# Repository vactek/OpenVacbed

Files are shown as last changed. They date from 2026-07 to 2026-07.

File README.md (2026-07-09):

# Guide

Work in progress

This is the guide to the Open Source VacBed by VacTek.
It works well with our AutoRegulator

TODO link to AutoRegulator

## Preface

This guide assumes you know what a vacbed is, how it works, and that you want to build one.
Sourcing is US-oriented. And, as you've heard 1000x before: Never use it alone!

### Features

+ Everything you need to experience a vacbed, and probably more!
+ Air-tight & quiet vac
+ Collapsible
+ Mask that takes pressure off the nose

## Supplies & Tools List

### General Tools

+ Sandpaper, around 150 grit
+ Silver Sharpie (for marking on PVC and latex; it washes off with Heptane) [Link](https://a.co/d/dIjm3Gn)
+ Measuring tape
+ Calipers (optional, but useful)
+ Philips screwdriver (for disassembling air pump)
+ Flathead screwdriver (optional, pry tool)

### Supplies for Frame

+ 2x 10-ft PVC pipe, 1" class (actual OD 1.315") SCH40 
+ 3x PVC right-angle joints
+ 2x PVC straight-through connectors
+ PVC T-joint
+ PVC ball valve
+ PVC primer and glue, or you can use a primer+glue combination
+ Any saw or pipe cutter to cut the pipe (or have them cut at the hardware store)
+ Metal file
+ 15 ft of bungee cord
+ Electric drill with a 3/16" drill bit (or around 4-5mm diameter bit) & 7/16" NPT bit for pressure gauge
+ Deburring tool or countersinking bit
+ Paper towels & dish soap (to clean the pipes)

Ensure all the PVC parts are the same size-class (1") and fit together.

### Supplies for VacBag

+ 6 yd of latex sheeting that is 1 meter wide, at a minimum. [Link](https://mjtrends.com/categories-.30mm,Latex-Sheeting). I recommend a transparent variant that is 0.35-0.50mm thick, and maybe get 7 yards. Thicker latex is easier to work with, but has less of a form-revealing effect. If you plan to incorporate a sheath, you must choose black 0.40mm latex as this is how the sheaths come molded. 
+ Glue: MJTrends Adhestex solvent-based latex glue. [Link](https://mjtrends.com/products.Solvent-based-latex,Adhesive,Notions). You can also use thinned Elmer's rubber cement, or an ammonia based glue (but it will not be sweatproof!) 
+ n-Heptane solvent (aka "Bestine")
+ Stainless-steel metal seam roller [Link](https://a.co/d/inTSm42)
+ Fiskars rotary fabric cutter w/ titanium cutting wheel
+ Fabric cutting mat, as large as you can get
+ Blue painters tape
+ Q-tips (a 50 pack should be plenty)
+ Microfiber cloth
+ Titanium scissors or just fabric scissors
+ X-Acto craft knife
+ Architectural compass
+ Popsicle sticks or paintbrush [Link](https://a.co/d/gNFQL3y)
+ Wax paper (about 75 sqft)

### Vacuum Pump & Misc Supplies

+ Hygger 10W 255GPH aquarium pump kit [Link](https://a.co/d/0ZdLTgu)
+ 1x Toothpick
+ Aquarium tubing to PVC adapter (3D-printable)
+ 12x Aquarium tubing combs (3D-printable)
+ Vacuum Gauge (0 to -100 kPa/-30 inHg/-1 bar) [Link](https://a.co/d/2pvzzVl)
+ Vacuum gauge adapter (3D-printable) 
+ Teflon sealing tape
+ Clear sealing medical tape 
+ Electrical tape [Link](https://a.co/d/5DU2WuV)
+ Clamps (3D-printable) [Link](https://www.printables.com/model/974751-clamp-print-in-place)
+ Talc powder (baby powder works, but must be rinsed off after each use!)
+ Meter-stick (used as a straight edge during construction and also to seal the bed afterward) [Link](https://a.co/d/iPwYZkS)
+ Silicone CPAP cushion [Link](https://a.co/d/0kk5ap6)
+ CPAP cushion breathing tube extender (3D-printable)
+ Silicone earplugs or swimming earplugs [Link](https://a.co/d/3BA8zx5)
+ BeGloss latex shiner

## Instructions

### Step 1: The Frame

+ Wash the outside of the pipes with dish soap and water then and dry with paper towel.
+ Cut the pipes: cut into 2x 34" and 4x 40" lengths (you'll have a little left over for the valve parts)
+ If you marked the pipes to cut them, remove any Sharpie marks with some Heptane on a Q-tip.
+ Add a slight chamfer to all the ends of the pipes with a deburring tool or sandpaper. 
+ Use a file to file down any logos or ridges on the PVC joints, then sand.

TODO glue the pipe joints: which specifically?
Glue one of the scrap pieces of pipe into one end of the ball valve. Do not glue the other end!
drill holes in the pipes every 6 inches and deburr or countersink then sand

### Step 2: Cutting the Latex

Cut the following shapes out of your roll of latex, in the order listed:

+ Main rectangular sheets: 2x 102" by 1 meter 
+ Bottom edge sealing strips: 2x 21.5" by 1.5" (or 1x 41.3" by 1.5" if you bought 7 yd of latex)
+ Corner sealing squares: 2x 1.5" by 1.5"
+ Repairing strips (optional): 6x 1" by 2"
+ Breathing hole reinforcing grommets: 2x 0.5" ID, 2" OD
+ Vacuum hole reinforcing grommets: 2x 1" ID, 2.5" OD

For circular cuts, put a couple of pieces of blue tape down on your spare latex (both sides!) and use a compass to draw circles of the desired diameters, then cut with scissors or X-Acto knife. Then immediately remove the tape.

Take note of which side of each piece is shiny and which side is dull. For consistency, we want all the shiny sides facing out and the dull side on the inside of the bed.

### Step 3: Gluing the Latex

+ Make sure to have adequate ventilation before you glue, it smells and is very bad for you!
+ To prepare for gluing, put down some wax paper and put blue tape on the backside edge of both pieces of latex you are mending. Also put blue tape on the front side 0.5" from the edge to mark where you need to glue.
+ Practice on a scrap first! It takes 15 minutes of drying before you can test a seam gently, and 24 hours to be completely cured.
+ The goal is to create a cylinder with both shiny sides out; using tape to support 10" at a time. Remove tape after each segment is completed.
+ After finishing one seam, start the next seam from the same end you started the first seam from, to prevent skewing.
+ Fix wrinkled seams as you go using Heptane on the tip of a small flathead screwdriver to pry up the edge of the seam.

glue bottom edge pieces with tape trick, making sure to overlap the two edge strips, then glue corners in essence,

"For the bottom seam, cut a strip of excess latex that is about 41.3 inches by 1.5 inches. Tape the end of vac bed with painters tape to seal it wrapping it around from top to bottom sheet sealing the seam. Then turn the vac bed inside out. The tape is to hold the seam in place. Glue the strip of latex you cut along the edge, only gluing the top half of the strip along the edge of the top sheet of the vac bed and then wrap it around and glue the bottom half of the strip to the edge of the bottom sheet, making sure it is centered so that about an inch hangs off each side. Fold and glue the 1-inch pieces to themselves. Glue the top of the extra 1” and fold it back over into the vac bed and glue it down. This will eliminate the extra hanging off on both sides and help seal the corner. Then take two 1.5” x 1.5” squares of latex and glue them over the corners to further seal. This time, glue them 3/4” on the top side and wrap them around the sides of the vac bed rather then the bottom edge of the vac bed. You should only glue a 3/4” x 3/4” square with excess material hanging off the side and bottom of the bed. Then first fold around the side of the bed, gluing this piece to itself with excess extending past the bottom of the bed (earlier when you did the long strip the excess went off the sides) then fold the extra around and glue it to itself. Having these two different parts with excess first going to the side and folding over and then another piece going orthogonal with the excess extending past the end of the bed and wrapping around is what seals it" - some guy, TODO attribution

Let dry. When you turn the bed right-side-out, there will be dimples in the corners.

cut outlet hole, 1.5" diameter, 2.75" from the end of the bed, right along the right seam
glue outlet grommets using tape grain trick

at this stage, add any necessary patches to weak points along the seam in the interior

Breathing hole placement: cut a 1" diameter hole at 29.25" from the top edge of the bed in the center of the top sheet. You can place your cutting mat inside the bed to use as a backing. glue breathing hole grommets too

### Step 4: Vacuum Setup

We need to reverse the pump so it sucks air instead of blowing. First, ensure it is not plugged in, as there are exposed high voltage wires inside. Then use a screwdriver to completely disassemble the pump, isolating the beige plastic fixture in the core. Inside, there are two air chambers with two one-way rubber valves each (small black circles). Remove these rubber valves by using a toothpick to push on the stem, and then insert them back in the same hole so they face the opposite side of the air chamber. Be careful not to break the stems! Reassemble and test the pump - on 50-100% power, you should feel some suction at the silver fittings on the front of the pump.

There are two clear tubes that came with the pump. Apply combs to the them every few inches for organization.
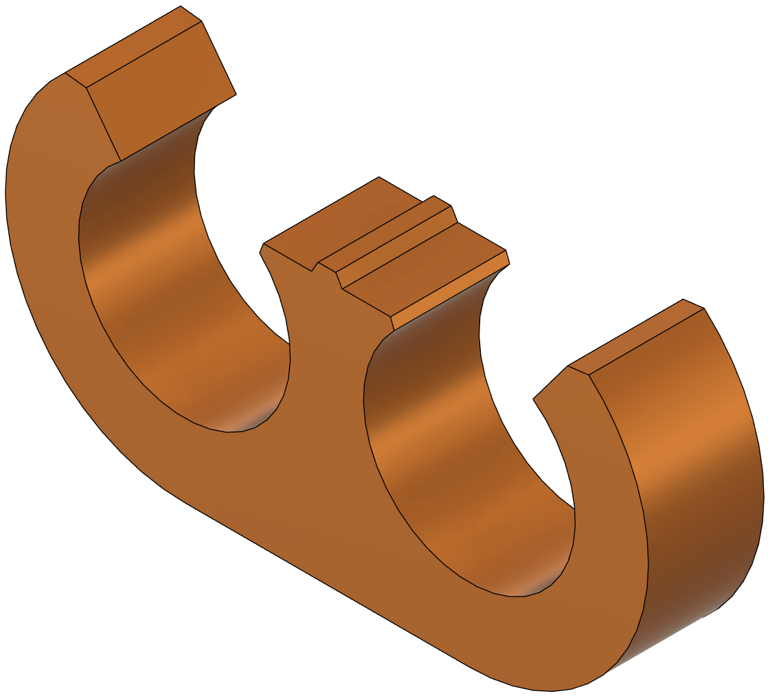
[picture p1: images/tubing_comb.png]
tubing combs 3D model


Tap a hole in the PVC pipe that connects the frame to the ball valve located where the pressure meter will go, then apply teflon tape to the threads and screw it into the pipe.

Press-fit the clear tubing onto the adapter. Wrap a single layer of electrical tape around the end of the adapter that goes into the PVC ball valve to give it a better seal. Insert the adapter into the outer end of the ball valve.
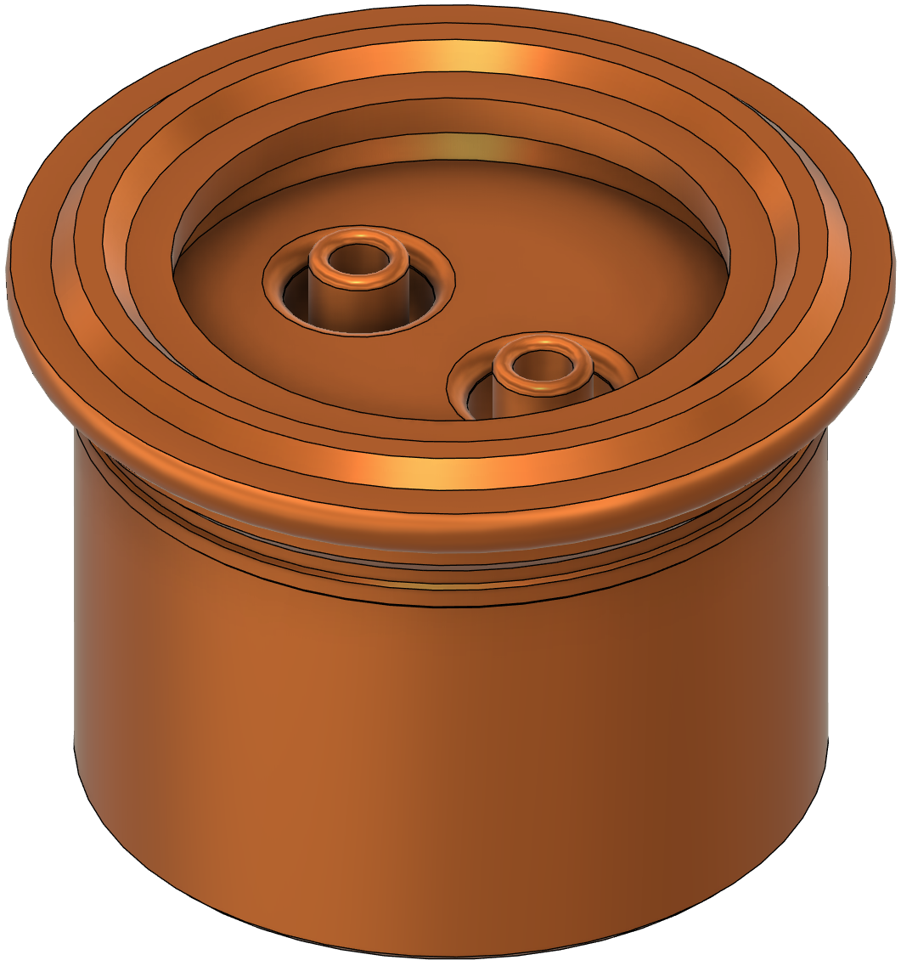
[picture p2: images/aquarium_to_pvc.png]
aquarium to pvc adapter 3D model


### Step 5: Final Assembly

< WIP >
powder and shine
optional assembly with pipes oriented the right way and elastic bungee cord setup
inflation test

cpap mask with tube or latex tubing (clean it first)

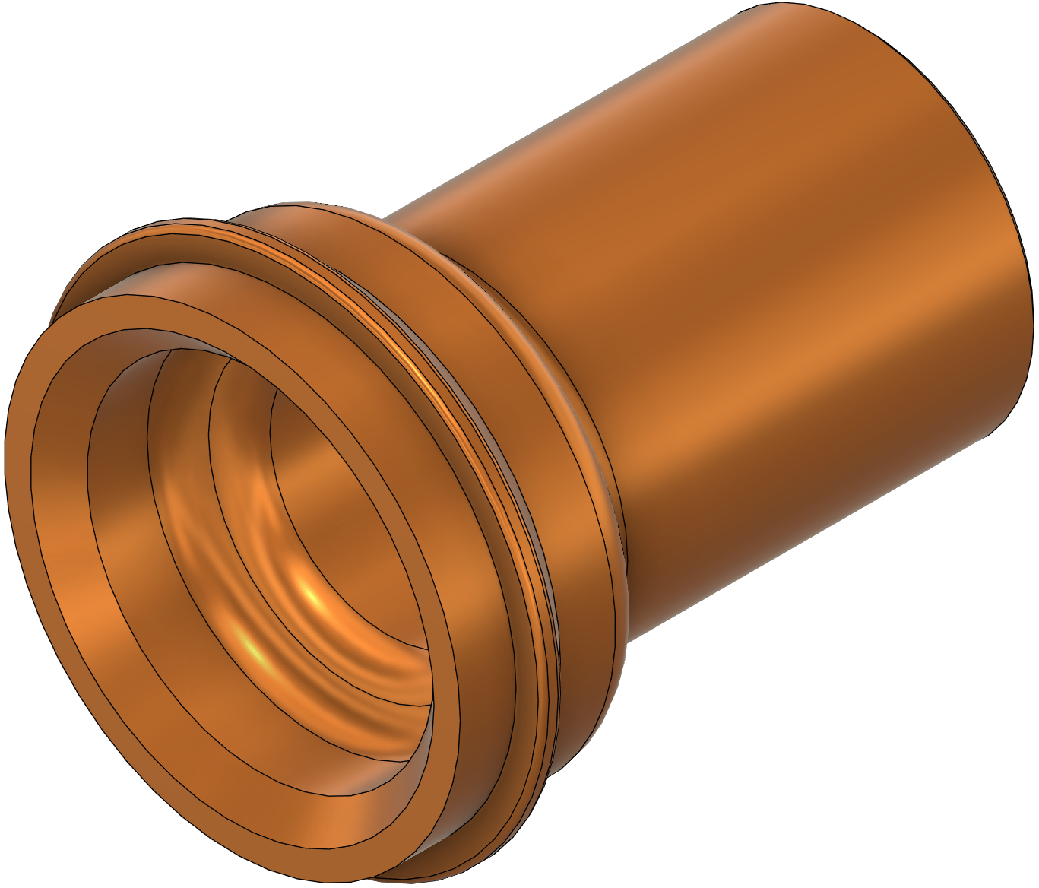
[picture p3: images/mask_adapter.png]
mask adapter 3D model


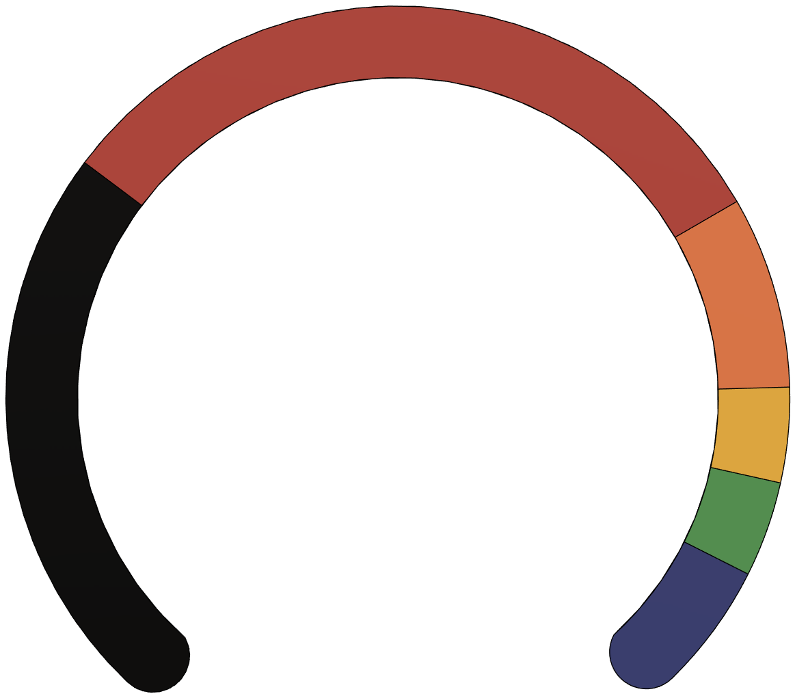
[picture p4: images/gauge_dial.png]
gauge dial


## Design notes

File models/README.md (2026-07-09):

# Models

## File Descriptions

+ PVC to Minivac: connect a T-joint of a vacbed frame to 3/16" tubing for use with a distribution block.
+ PVC to Dual Minivac: connect a T-joint of a vacbed frame to 3/16" tubing for direct use with an inverted aquarium pump.
+ Tube Comb: organizes your long doubled-up 3/16" tubing runs

## Printing

All models in this directory are designed to be printed in PETG.

The settings aren't terribly important - they all worked fine on a 10+ year old printer with a 0.6mm nozzle.

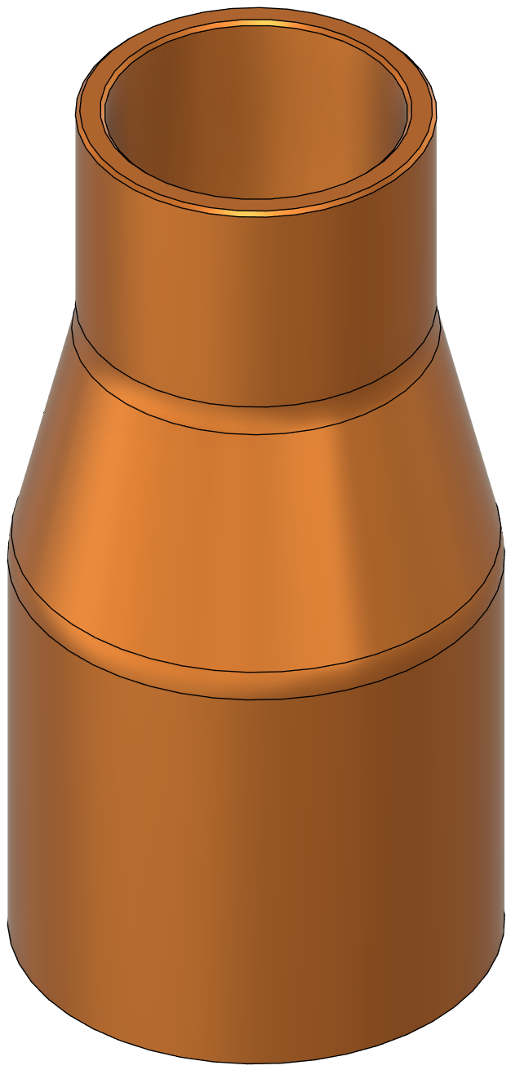
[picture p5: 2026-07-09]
images/vacuum_to_pvc.png

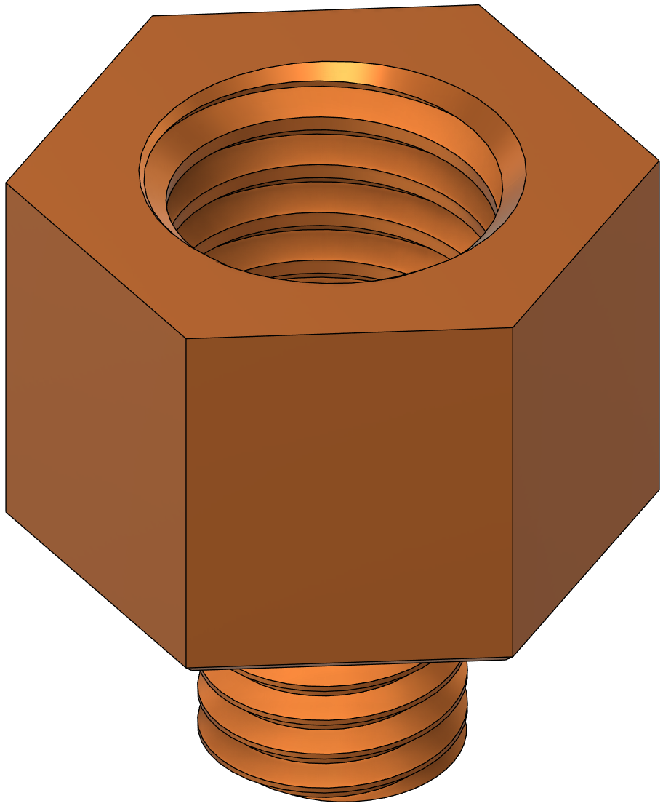
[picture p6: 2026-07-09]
images/M10_to_NPT.png

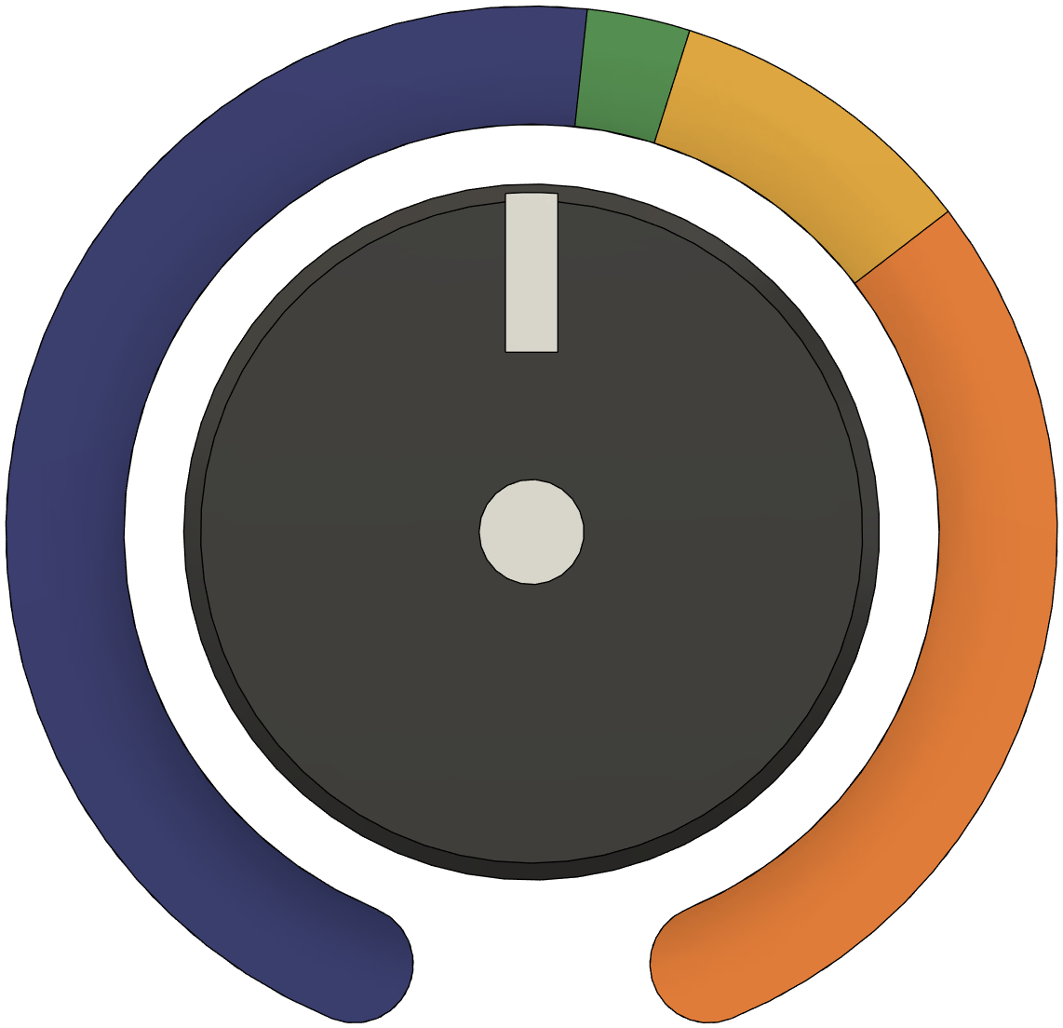
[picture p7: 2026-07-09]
images/pump_dial.png

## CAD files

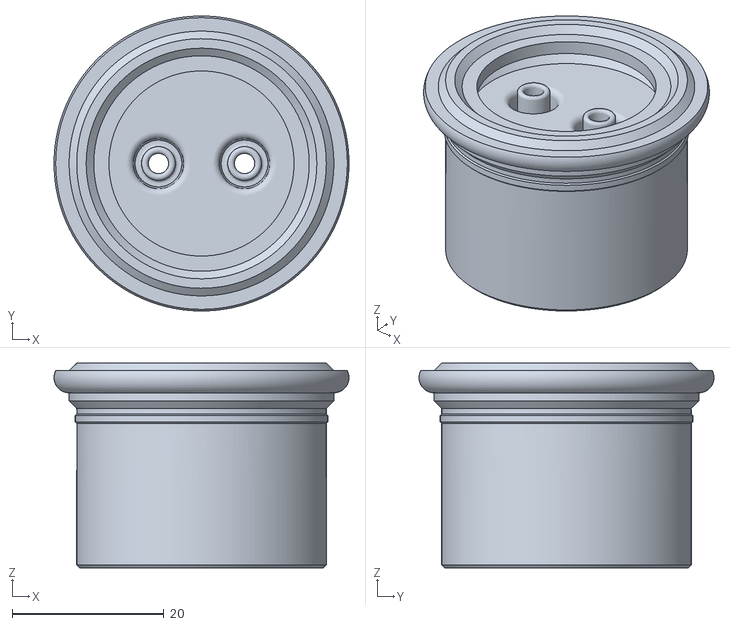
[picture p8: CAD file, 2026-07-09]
models/PVC to Dual Minivac.stl
38.9 x 38.9 x 27.0

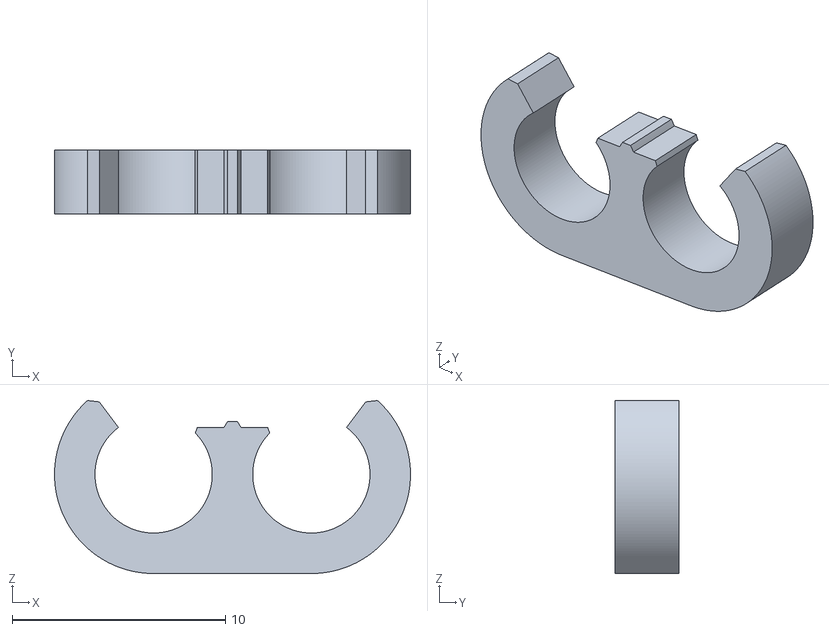
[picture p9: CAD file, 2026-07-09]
models/Tube Comb.stl
16.7 x 3.00 x 8.12

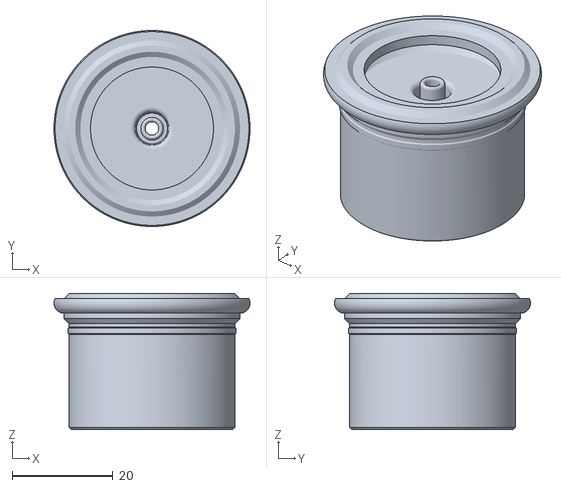
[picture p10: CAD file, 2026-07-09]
models/PVC to Minivac.stl
38.9 x 38.9 x 27.0
